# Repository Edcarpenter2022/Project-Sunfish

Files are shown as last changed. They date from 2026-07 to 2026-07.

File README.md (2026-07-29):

# Project-Sunfish
Summer internship project funded by the University of Idaho

**Project Authors:** 
&nbsp;&nbsp;&nbsp;&nbsp;led by Ethan Carpenter, supported by Isaiah Preston and Karson Vordahl 

**Project Supervisors**
&nbsp;&nbsp;&nbsp;&nbsp;Dr. John Shovic and Dr. Marz Everett 

# Overview

&nbsp;&nbsp;&nbsp;&nbsp;Project sunfish is designed to eliminate costly manual sampling of lake Coeur D' Alene. The current process requires a boat trip to the verified satellite locations where there are indicators of harmful algal bloom and heavy metal contents, and the completion of the manual sampling process, which entails collecting each sample individually, at 3 separate depths. Once collected, these samples are then safely, and without contaminating, dumped into a sampling container and then put into a cooler. These samples then are only considered "fresh" for a certain ammount of time before they are not useful for testing. The limitations introduced by this process are the costs and availability of the boat, as well as personnel to operate the boat and take the samples, this operation also has a limited window of time where this can successfully be completed, you cannot take the boat out in the winter time therefore you can not sample the areas in that time, resulting in months of no data collected. 

&nbsp;&nbsp;&nbsp;&nbsp;Sunfish will solve many of these problems and more. Sunfish is a commercially available drone produced by BlueRobotics, and assembled in 2019 by a previous graduate student. It has since been converted to serve this purpose, by designing and retrofitting an automated collection device, for taking samples, as well as adding relevant equipment to create a cohesive device. 

# Phases

There is three main phases to this project

**Phase one:**
&nbsp;&nbsp;&nbsp;&nbsp;Restoring Sunfish back to "factory" configuration and hardware to ensure working components and testing

**Phase two:**
&nbsp;&nbsp;&nbsp;&nbsp;Developing automated collection device and testing

**Phase three:**
&nbsp;&nbsp;&nbsp;&nbsp;Testing components together and collecting samples with sunfish

# Phase One

&nbsp;&nbsp;&nbsp;&nbsp;After retrieving Sunfish from storage, the first task was opening up both enclosures and cleaning all of the components. After sitting in storage for 4-5 years, Sunfish needed a tune-up.



First look at sunfish once pulled from storage

&nbsp;&nbsp;&nbsp;&nbsp;This was done by removing all of the electronics from the enclosures and unseating all of the connections. This was done over the course of 2 days, cleaning and identifying and labeling what each of the components do and where they are located. This allowed me to see what we had and what was unneeded for the project and what components couldn't be sacrificed. 




Electronics, and how they were seated in the main enclosure 



Sunfish with all of the enclosures removed and the electronics off the frame



Electronics cluster after putting everything back together the first time

&nbsp;&nbsp;&nbsp;&nbsp;After the completion of our first successful dive, we identified some small issues and somethings that needed to be fixed. There was a small leak in the main enclosure, during the dive the enclosure took on about 2 tablespoons of water, and one of the main steering thrusters on the front side was non-operational. After further inspection of the non-operational thruster, it appeared that while in storage, there was stagnant water inside the thruster itself on the brushless motor and corroded part of the thrusters battery housing, which caused the motor to then grind on itself and cause damage to the thruster itself. The solution was simple, the non-operational thruster was then moved from the primary steering position, to one of the "extra" slots available on the top side, used for surfacing the drone, this slot was available and did not affect any operation of the drone due to this being part of the optional "heavy thruster configuration" that was purchased, which added an extra 2 thrusters to the surfacing (or top side) portion of the drone. Once swapped the next challenge was identifying and fixing the leak.

&nbsp;&nbsp;&nbsp;&nbsp;Each enclosure housing has three separate parts to it, 2 end caps, which split open to 2 different parts each, and the acrylic tube itself. So, taking apart each component of the housings, each o-ring was replaced and a fresh coat of silicon waterproofing grease was applied. After putting the enclosure back together a pressure test was conducted.(See "Conducting a Pressure Test") Once reached 15mm/hg, it needs to sit for 10 minutes, if the pressure drops below 14mm/hg in that 10 minutes the pressure test is considered a failure and is not safe to put in the water. The sub continually failed these pressure tests, it was pointed out that it might be the enclosure itself, so we swapped the factory 12" acrylic enclosure tube with a 18" acrylic enclosure, nicknamed "Extendo-Tubo". Once replacing the tube, the leak slowed, but it was still failing the pressure tests. To be through, before ordering all new components,  I removed each of the plugs on the back of the enclosure, these seating screws have the wires leading to each of the thrusters as well as the lights and the battery enclosure, protruding from the back, in order to unseat these screws, you have to remove the thrusters from their mounted position. After removing the enclosure bolts, you will see a small o-ring on the inside face of the bolt, all 18 of the o-rings were pulled, replaced and re-greased. They were then screwed back in and torqued by hand to the correct positions. The same was done for the smaller cap screws that are used to hold the 2 different parts of the end caps together. After replacing and torquing them down with a Allen key by hand, Another pressure test was conducted, this test passed and we were ready for our second successful dive (see "Prepping For a Dive").

# Conducting a Pressure Test

&nbsp;&nbsp;&nbsp;&nbsp;In order to conduct a proper vacuum test, you will need the provided vacuum pump. 
- Ensure both the brass male pieces have intact o-rings, and there is no debris on them.
- Seat each male end inside the female ends on the rear of the sub, one on the rear of the main enclosure and the other on the rear of the &nbsp;&nbsp;&nbsp;&nbsp;battery enclosure, the female ends are labeled "Vent"
- Depress the handle of the vacuum pump, effectively removing the air from both enclosures
- To achieve a 15mm/hg readout on the face of the pump, it will take about 300 depressions.
- Once the needle is reading 15mm/hg set a timer for 10 minutes and place the pump somewhere upright and secure (if the pump is not upright, it has been noticed that it will affect the interior pressure for some reason, my guess is that it causes the tube to twist, therefore adding pressure into the enclosure)
- After the 10 minutes is up, if the reading is between 15mm/hg and 14mm/hg, it has passed and you are safe to dive, if the reading is below the 14mm/hg line, it has failed, the first step should be to remove the caps from the enclosures and inspect for debris along the o-rings and repeat the steps above.

# Prepping For a Dive

&nbsp;&nbsp;&nbsp;&nbsp;Congradulations! if you are reading this, you have passed the pressure tests and you are ready to dive.

&nbsp;&nbsp;&nbsp;&nbsp;You will need the following items:
- QGroundControl software installed on your computer, if you're using your personal computer for the dive, or one of the two computers that come with the project has the software already installed. 
- Sunfish itself
- Battery for the sub (this should be charged before the dive fully so it does not die in the water)
- 300 meter tether (this is the spooled tether)
- smaller tether (This tether is wrapped up in the backpack and is used to attach to the spool, and then to the fathomX interface box)
- Fathom X interface box (blue box with a power cord found with it)
- Fathom X interface box power cord
- USB cable that attaches the Fathom X box to your computer
- Xbox controller (wired or wireless)
- Costco wagon (so you can load everything into the wagon and transport to the launch site)
- Sunfish backpack (in this backpack, you will store everything but the sunfish and the 300m tether, inside the backpack is a flat tackle box tray that holds extra components that you might need as well as a wrench that fits the enclosure cap screws. I suggest throwing in a IFIXIT setup so you can easily remove the smaller cap screws)

&nbsp;&nbsp;&nbsp;&nbsp;Before loading everything up in the wagon and making the trek to the launch site, you need to do a couple of things first.

- You will need to ensure that there is no leak in the enclosure, always perform a pressure test before you go out for a dive, even if you tested the day before and it passed, something might have changed overnight that is unseen, always do a pressure right before you leave for launch, or if the sub experiences a lot of jostling around during transport, you will need to perform one at the launch site.
- Boot up QGroundControl and run through the diagnostics, this is done by following these steps which are provided on the BlueRobotics web page
  &nbsp;&nbsp;&nbsp;&nbsp;https://bluerobotics.com/learn/bluerov2-software-setup/#installing-qgroundcontrol
- Once you have completed the Sensor Calibration you need to ensure that in the "Vehicle Setup" tab, under "Frame" you need to ensure the BloueROV2 Heavy/Vectored 6DOF setting is enabled. Remember, that after each calibration setting that is changed, you have to reboot the vehicle entirely.
- After successful completion of these steps, the previously yellow bar on the top left of the screen, will turn green and say "Ready to Launch"
- You then are ready for your launch and are ok to load everything up and head to your launch site

&nbsp;&nbsp;&nbsp;&nbsp;**Launching** 

- When at your launch point, remove everything from the wagon and set up your area
- Make sure you have QGroundControl launched on your computer and the Fathom X Topside Interface plugged into your computer
- On the back of sunfish there is a male plug, plug the matching female end from the spooled tether into that and secure it multiple times with electrical tape to ensure it is fully waterproofed.
- Then connect the looped end of the tether, to the carabiner clip attached to the sub. This makes it so if you need to retrieve it for any reason, you can pull on the tether to reel it back in and not put tension on the plug itself. This is what the tether is made for.
- Hook the smaller tether to the spool side and then to the Fathom X Topside Interface
- Plug in the Xbox controller to your computer.
- You can either choose to place the sunfish in the water gently, or toss it in from the dock if you are on a dock, if you are just on the embankment of a river or the lake, do not throw it, place the drone in the water, so it is all covered, you are going to want to have enough submersion so it can have plenty of room to move up and forward so it doesn't scrape on the bottom.
- It is also a wise idea to have someone in the water with sunfish, two people are preferred if you are launching off a dock, and one person suffices if you are launching in a shallower area.
- Once the sub is fully submerged, click the green "Ready to Launch" button. a small slider arrow will pop up on the bottom of the screen the reads "ready to arm" slide this to the right and the sunfish will arm and then be operational.

&nbsp;&nbsp;&nbsp;&nbsp;Congratulations on your successful dive!

# Automatic Sample Collection Device

&nbsp;&nbsp;&nbsp;&nbsp;The current prototype is what I am calling a "dry prototype" this means its not waterproofed, or ready for diving, only a concept of what this will look like and how it can function, without tackling any of the waterproofing factors. The design consists of a 3D printed honeycomb enclosure that encases a bag with a silicon tube. There is also a "lid" that vertically slides into place over the mouth, that has a channel you can feed the tube through, the tube will end up facing vertically out of the channel, in line with the cover. Inside the tube is placed a ball check valve that has been 3D printed and designed by Ethan Carpenter, this consists of, 3 parts, the "stem", which is a short pipe, which graduates into a wider pipe with a little shelf in the middle for the spring to sit on. the "spring and ball" which is exactly what it sounds like, a spring attached to a ball. Finally the "Cover" this cover has an o-ring attached to it and gets superglued over the spring and ball, creating a seal. 

&nbsp;&nbsp;&nbsp;&nbsp;The plan is to have a Dynamixal servo motor (either the AX-18a or the AX-12a) push down on the ball, releasing the pressure and causing the bag to fill with water. when the sample is completed, it will then release the downward pressure it is holding on the ball and then cause the water flow to be cutoff. This design has been tested without the Dynamixal, and has shown one issue that I have seen. The main issue is that the bag, being deflated and no air inside, so to not affect the buoyancy of the sub, needs some sort of external force placed upon the bag encourage it to open. This is how we avoid using an actual pump at the end to pump the water in. I have thought of attaching somehow a spring to both sidewalls of the bags and then to the outer honeycomb enclosure, that would, when the ball valve is open, force the bag to open, therefore sucking water in and filling it. but I don't think that there is enough force applied by the spring to suck that much water in, this could be because the tube itself is at a 90degree angle, so there is limited room for the water to come in, as well as not enough pressure to pull water inside. The second idea I had, was having a compressed spring inside the bag, it would need to be powerful, and sterile so it docent affect the sample, but if it were compressed inside the bag, and then once the tube is open, it expands, that might create enough force to pull water in, of course then you would have a spring in your sample and then need to get it out. One other idea I had was to create a new bag system that made it so the bag itself was filled with air, and being submerged, this added air might counteract the weight added by the collection device. This would also mean that we would need to add a vent hose out of the top of the bag, so when water comes in, the air isn't escaping through the same hole.



&nbsp;&nbsp;&nbsp;&nbsp;Ball check valve 3D printed Prototype 




&nbsp;&nbsp;&nbsp;&nbsp;3D printed honeycomb enclosure




&nbsp;&nbsp;&nbsp;&nbsp;Lid with sampling tube fed through

# List of components both on and extra for Sunfish 
&nbsp;&nbsp;&nbsp;&nbsp;Components that are currently on and infuse of the sunfish will be bolded, extra components will not be 

- **18 inch enclosure tube**
- 12 inch enclosure tube
- **Acrylic dome lid**
- **rear end cap aluminum lid with 18 port holes**
- **8 inch acrylic battery enclosure**
- **aluminium endcap for battery enclosure**
- **aluminium endcap for battery enclosure with 4 port holes**
- **2 cradles for battery enclosure**
- **2 cradles for main enclosure**
- **6 fairings with buoyancy foam**
- **Pixhawk flight controller** with original box and instructions
- **Raspberry pi 3 + SD Card**
- **Motor terminal block, x2 3 slot housings, and x1 1 slot housing**
- **7 Electronic Speed Controllers (ESC)**
- **Fathom-X Tether Interface Board**
- **Mount to fix camera to front**
- **"Wire guard" located in the "back" of the enclosure between the main "board" and the endcap, used to guide wires through to keep organized**
- **2 lights (one wire lead)**
- **8 thrusters, labeled 1-8, (thruster number 1 is non-operational and has moved to the topside)**
- **Skid plate**
- 2 fairings, one with foam
- **6 7oz ballast weights**
- Big bag of dry&dry Desiccant
- 2 lithium ion batteries (14.8V, 18aH)
- Bag of extra plug screws
- Bag of O-rings
- Bag of plugs for testing your vacuum pump
- 2 Vacuum pumps
- 8 inch aluminium enclosure with both endocarps, this contains a dissolved oxygen sensor with all hardware inside, this has not been tested or touched during this project
- BlueRobotics newtonian gripper
- 3 BlueRobotics depth ping sensors
- Acrylic battery enclosure
- 14 hole (non-threaded) enclosure cap
- 2 full setups for battery enclosure caps
- VGA to USB-A adapter for camera use (removed because it was spliced incorrectly, as well as non-operational and un-needed)
- 3 bags of moisture sensors and relevant pieces
- 2 wired Xbox controllers
- Fathom X topside interface
- Bag of 2 SD cards (copy of sunfish with no access points, has mavlink interface and some test programs from previous student, desktop PI GUI added, Python 3 added
- "Tether" to connect the Dissolved Oxygen sensor to the main enclosure and the PI
- Tackle box insert with extra hardware/ diagnostic tools for dive
- 4 notebooks and manilla envelope of relevant documentation (from previous project leads, both project Catfish and Sunfish)
- External hard drive containing Sunfish dive documents, videos, and reports
- 2 laptops, both containing relevant documentation and were purchased for these projects as well as the chargers
- GoPro used for project, but resides with Marz Everett
- Battery charger with original box
- Sunfish Backpack
    - AC/DC power bank with charger
    - Small tether used to connect spool to Fathom Topside
    - Misc. zip ties
    - Silicon grease
    - Electrical tape
- Costco Tote
    - Minnow drone, disassembled, but some components work and you can use to test code or hardware on it
    - Battery for powering Minnow
- Automatic collection device
- Potentially the Dynamixel servo motors with a Pi 3

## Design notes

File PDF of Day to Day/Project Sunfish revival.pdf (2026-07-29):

Project Sunfish revival

https://bluerobotics.com/learn/bluerov2-assembly/#introduction

5-28-26

- Found laptop passwords
- Took apart electronics inside enclosure and sorted components into different piles
- Cleaned inside the battery enclosure and re-greased o-rings in all acrylic tubes.
- Tore down ROV2 to the “factory” setup
- Identified components added from OG project
- GPS sensor in main electronics tube
- Buck Converter attached to main battery to get power and main board housing inside main tube
- Vernier optical dissolved oxygen probe with complete setup
- Added missing structural bolts to the frame and tube clamps themselves

5-29-26
- Start to put the main board back together
- Removed GPS/compass from pixhawk

●

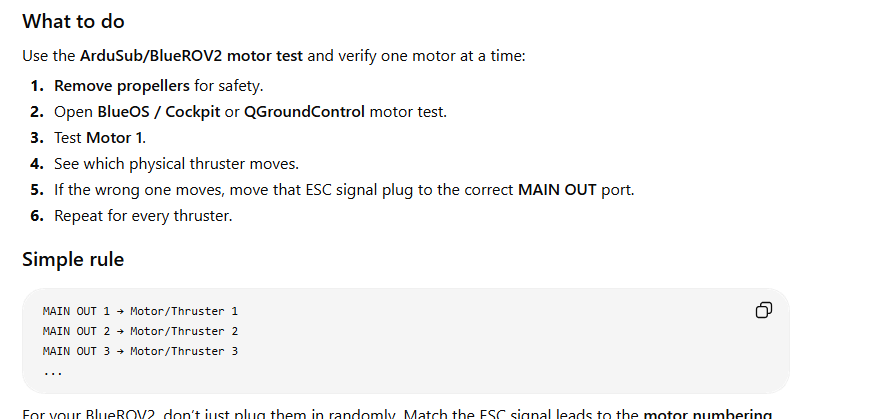
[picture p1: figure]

- Need to do motor test next week
- Replaced water sensors, The “sponge” in the enclosure was expanded meaning there was moisture collected, either from long term storage and the sponge collecting moisture from the air, or actual water introduced to the system. I am more confident that it was moisture pulled from the air due to the storage factors.
- Replaced communication wire on the moisture sensor board as a precaution.
- The board is probably 75% completed!

6-1-26
- Connected the rest of the board and put together the enclosure

6-2-26
- Re-wired the inputs for the Pixhawk
- Added the remaining 2 ESC units and wired them to the 2 thrusters left
- Ensured all connections were tight, re-soldered and shortened some cables.
- Performed vacuum test number 1 : Passed!
- Performed vacuum test number 2 : Passed!
- Removed battery from chassis and placed on charger
- Found issue with tether connection, doesn't connect to itself so we don't know how we can control it.

6-3-26
- Took apart enclosure and added ethernet cable connections, and connection from pi to pixhawk
- Performed vacuum test number 3 : Passed
- Pulled apart board and drew board diagram
- Identified potential issue with tether connection

6-4-26
- Found tether issue
- Made tether pin layout/diagram with connections
- Put board back together and performed vacuum test 4 : Passed
- Connected depth sensor
- Performed vacuum test 5 : Passed
- Set up ground control on Ethan's laptop
- Went through sensor setup
- ROV2 is ready to test in water, test date is thursday june 11th at 6:00am

Relevant documentation

https://bluerobotics.com/wp-content/uploads/2019/02/BlueROV2_heavy.pdf Blue rov2 connections

https://www.ardusub.com/introduction/hardware-options/connection-diagrams.html Connection diagrams

https://bluerobotics.com/learn/bluerov2-software-setup/#installing-qgroundcontrol ground control setup

https://www.ardusub.com/introduction/hardware-options/required-hardware/tether.html hardware setup with tether

https://bluerobotics.com/learn/wl-connector-standard/#tether standard connection

6-5-26
- Logo design

6-8-26
- Performed vacuum test number 6 : Passed
- Plugged vent holes
- Researched plug for loose end connector, best option might be to 3d print one and throw an o-ring in
- Pretty sure I identified the random cable. I believe it is the power/data cable for the doppler velocity log.
- I identified that the manufacturer did not intend the drone to be operated without the tether attached.
- SEACON Underwater Wet-Mate Connectors is the cable used
- The vga cable is used for the doppler sensor, can be removed
- I believe it would be a good idea to add the ping sonar that we currently own, it would add a “failsafe” if the camera feed from the drone fails so we wouldn't crash into anything

6-9-26
- Reviewed all of the flight logs that Amanda completed to determine how and when the camera failed
- Re-wired the camera, fixing the problem unless the camera is fried due to the failed ground wire from the previous use.
- Attempted to unscrew the back caps of the enclosure to add the sonar sensor
- Safely and securely wired sonar sensor into the BLUART converter that allows it to be converted to usb, and then plug into the pi
- Removed the entire serial cable to usb as well as the “extra” tether that is used to communicate to the doppler sensor.
- Re-cracked open the enclosure to adjust orientation so the pixhawk would be facing starboard, therefore the gyroscope would be accurate
- Removed buoyancy foam to remove the final add ons from the previous project
- Re-attached the skid plate for safe sonar mounting, there were no available mounting slots for the sonar that would be safe, so the skid plate is now on
- Zip-tied the cords out of the way for a more clean/unimpeded thruster ability.

6-10-26
- Plugged in Sunfish to battery and connected to QGC to test camera and see if sonar was working.
- Camera does not seem to be working still.

6-11-26
- Prepped for first dive, made sure calibration was good, and all sensors were plugged in
- Checked to make sure all thrusters were plugged in
- Booted up Qground control and tested xbox controller.
- Made a few tweaks with the sunfish and all of the wires and thrusters.

6-12-26
- First dive!!!
- Thruster number 2 does not turn when in water
- There is a grinding noise when in water when turning it to the right, possibly the thruster itself, maybe another thruster grinding on something while attempting to turn
- Sub is a little too heavy, have to remove some of the ballast weights
- There is a small leak in the main enclosure of the sub, after being submerged at different depths for a consistent 10-12 minutes, there was about 5 tablespoons of water in the enclosure, nothing touched the electronics, only the wires, and everything from the outward view is still operational.
- I'm pretty sure the leak was due to a small gap between the cap and the enclosure as well as not lubricating the o-rings with silicon before the dive.
- Need to get more familiar with the controls as well as possibly investing in a wireless xbox controller, the wired one made it decently hard to navigate to a good vantage point while connected to the laptop
- Need to get a better look at the screen while diving to see what controls i can see and sensors are working, i know on the blue robotics page, there is a new operating system where you can customize your home screen and put different readouts/panels in the main view, worth looking into
- Need to research new thrusters, a new thruster from blue robotics with an extra fin is $240, there might be some in longterm storage that we can find.

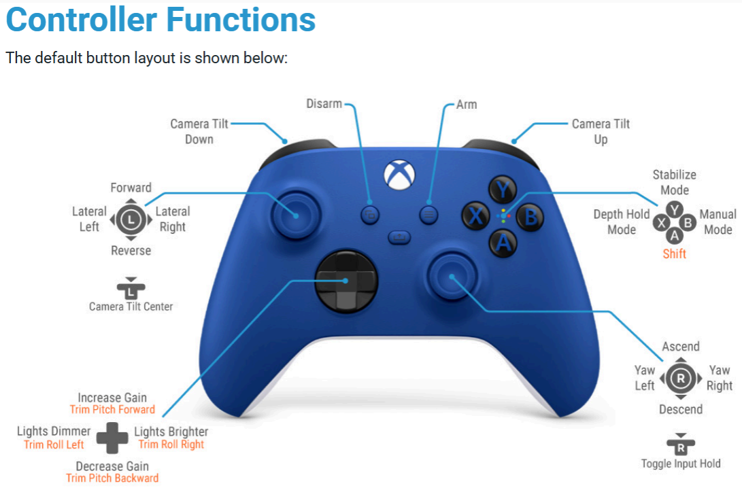
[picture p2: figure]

- Above is the controller mapping
- I also dont know if the camera tilt works, I am pretty sure that i can test it outside of water though, The only part that we need might be the actual camera from blue robotics, which is $134.40 without shipping domestic shipping is $6.50, 2 day shipping is $35.90

6-16-26
- Dive date!!!
- Sunfish did not pass the leak test, there was too severe of a leak to safely perform the test today. Karson and I replaced the tubes for the vacuum pump as they were leaking, as well as took off the enclosure lids on either side, both the domed one and the corded one. And inspected for any hairs or debris that caused the improper test. Could not find anything. I suspect that the leak is coming from some sort of crack in the acrylic tubing, there are many scratches on the tubing itself and that could cause a leak. There was also a small leak that looked like it was allowing water in the underside of the sub, in the same position as the last leak, so I am confused as to why this is still happening. When I return on Monday the 22nd of June, I will investigate further and try to find the issue.

6-22-26
- Took off the 12 inch acrylic tube that I thought had the leak and replaced it with the 18 inch acrylic tube. For the 18” tube I made a board mount like the one attached to the camera to make it more stable for the actual board itself
- Vacuum tested the 18” tube and the pump was saying there was another leak. It wasn't constant but it was also hard to get up to pressure, making me think that it is the actual vacuum pump that is the issue. There are some other vacuum pumps on amazon that are available, there is the style of the one we currently have for around 15-20 and the more robust one for 57 without any tubes i think. Will investigate more tomorrow

6-23-26
- Tested vacuum for 18” tube and still failed, next step is to replace battery housing
- 3D printed and modled different camera mounting systems, as well as created internal skeleton to help with the stability of the camera in general

6-24-26
- Performed testing on why the camera was not working, turns out its the actual camera itself, not the board. Need to look into buying a new tested camera
- Hooked up QGround Control to Sunfish and tried to map out what channel the lights are on and decided that the lights are indeed not working, either from frankenstaining the wires or bad wiring in general. Need to look into further
- Replaced battery housing enclosure
- Preformed vacuum tests to ensure vacuum

6-25-26
- Pulled cap plugs out and re-greased and replaced some of the o rings on certain plugs.
- Opened the enclosure and un-seated wires, re-routed most of the wires to make it a cleaner fit inside the enclosure, no more rubbing wires, plus that allowed me to ensure things were connected properly as well as double check the thruster inputs
- Opened most cap o-rings and replaced grease in them, some used the bad type of grease, cleaned and replaced all

6-26-26
- Put enclosure back together with everything wired together, this both fixes the orientation of the pixhawk for the gps issue that we were having, as well as it allows me to ensure that the seals on the inside are tight
- Tested each individual tube with the vacuum pump, turns out i think that it is the connection between the pump itself, we found an stl file that we are printing currently to test the vacuum out on.
- Will try and update on monday

6-29-26
- Attempted to find and fix pressure leak, unsuccessful, will try again tomorrow

7-1-26
- Re sealed enclosure and connected all of the bulkhead connectors
- Small leak is still there, but definitely slower, I don't really know what it could be outside of that besides some connection issue, but i will figure that out on monday

7-9-26
- Put all dome mounted plugs back in with re-greased O-rings and torqued down the cap screws with an allen wrench, performed the first pressure test after re-assembly : PASSED!

7-10-26
- Took time lapse video of putting sunfish back together for social media, re-wired everything and seated everything back together. Performed Pressure test #2 : PASSED!

7-13-26
- Preparation for dive #2
- Dive #2 was a success!
- Thruster number one is still non operational, and therefore causes the sunfish to descend into water unevenly
- Thruster 2 looks like it is always on

7-20-26
- Work on developing the automatic water collection system
- Idea: Have a 3D printed honeycomb cage around a scientific ziploc bag. The bag needs to have a relatively wide opening, about the width of a quarter. This is attached to the ring of the cage. Attached to the cage, there is a flip top lid with a servo motor attached on top, or on the side. There is a spring holding the lid closed with constant pressure. The servo motor will then open the flip lid and let water in, when it is full, after a certain amount of time, the motor will release and the spring will cause the lid to snap shut, locking the water in the bag. These need to be all individually working, and there needs to be 3 different mounted collection systems. The bag will also need to be easily removable and replaceable without letting any contaminants come in contact with the sample
- 3D printed collection housing cage, and developed one idea for the lid
- Coded three servos to operate off one pi

7-21-26
- Modeled and Printed another design for the lid which allows a catheter type silicone tube to go through it and then be clamped off
- Coded a servo to clamp the tube, release the clamp to have the bag fill with water, and then clamp it again. The problem with this is if there is any movement in the servo itself, the positioning will be off and therefore not create a closure in the tube.
- Marz thought getting a different, more powerful servo would be a good idea, She is removing the one from the Boeing robot downstairs.

7-24-26
- With the help of Marz, figures out how to wire the dynamixels correctly and then also code them to starting position, 90 degrees closed, and then back to starting position. The positioning of the motors itself is repeatable and able to be produced more than once.
- Polished ideas for collection system, we will end up using a rubber duck bill valve to keep the water out, then the servo motor will apply pressure against it and then open it, when collection is complete, the servo will then remove pressure and seal the collection bag.

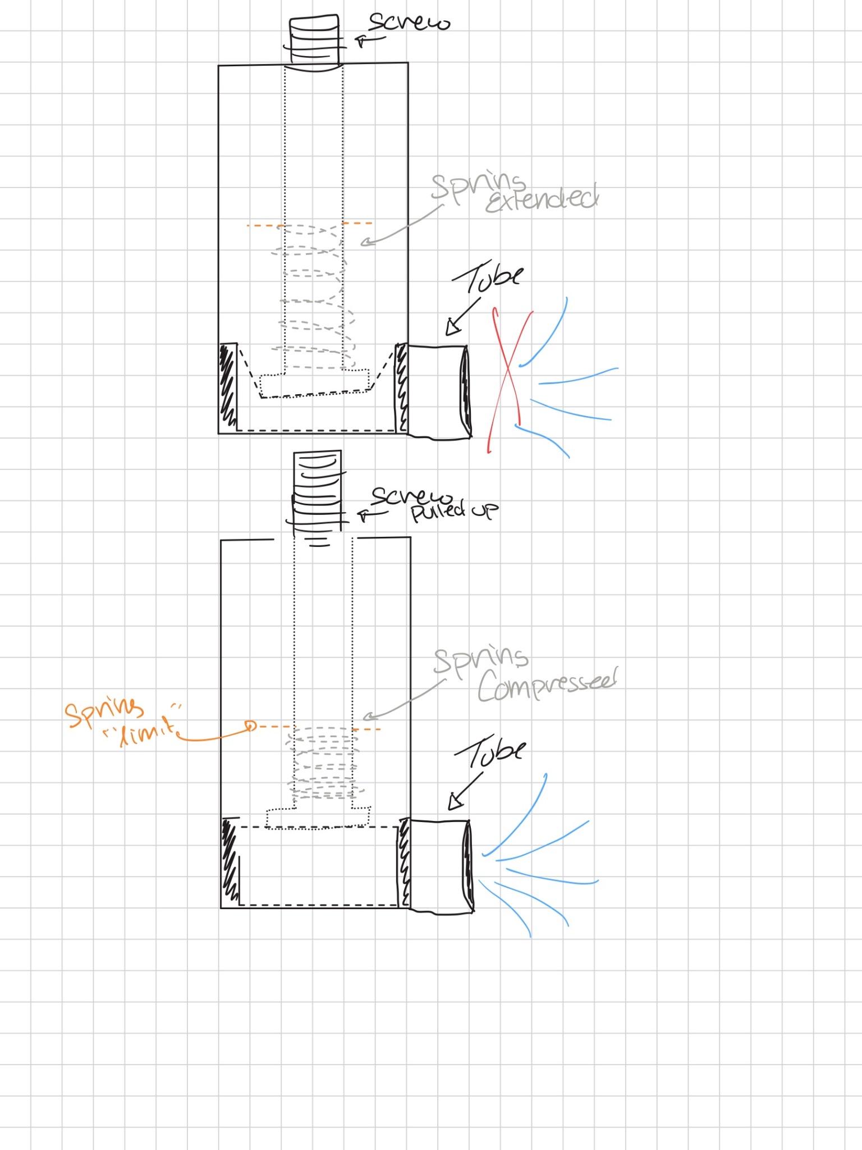
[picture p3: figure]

●

7-28-26
- Developed 2 prototypes of the sampling device, also developed and implemented a ball check valve to slip inside the collection tube, this will allow the bag to not be contaminated by any other samples.
- Started writing Github repository for the project.

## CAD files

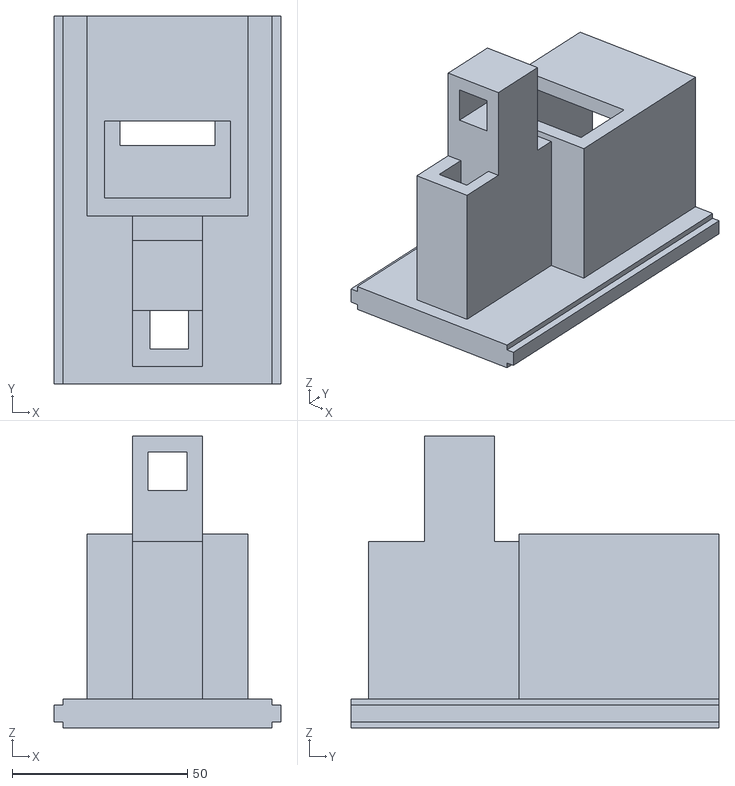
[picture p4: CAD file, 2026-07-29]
STL-Files/Lid prototype 4.stl
64.8 x 105.0 x 83.2

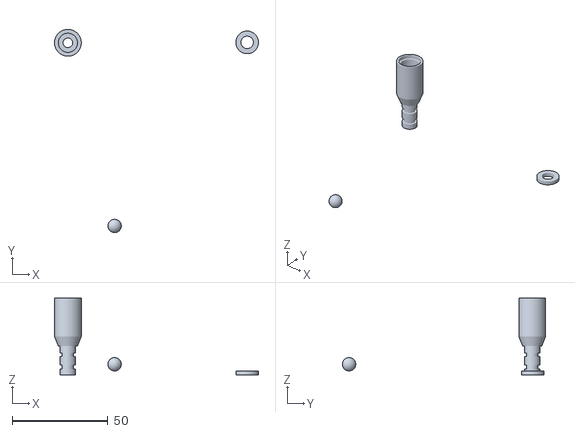
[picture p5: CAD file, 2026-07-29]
STL-Files/ball check valve 4.3.stl
106.6 x 106.2 x 40.0

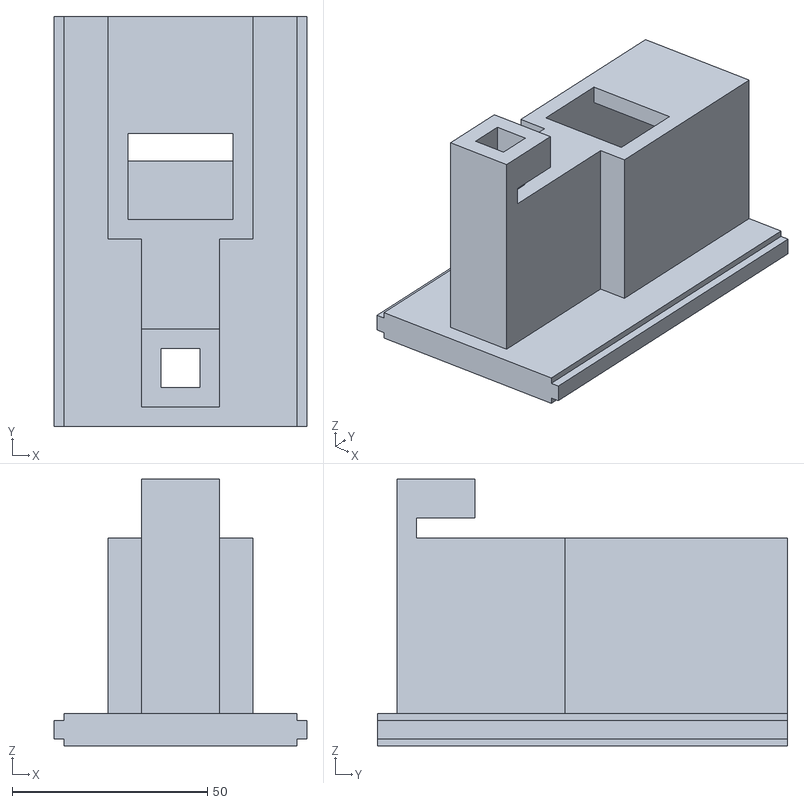
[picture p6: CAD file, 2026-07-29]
STL-Files/cover prototype 2.stl
64.8 x 105.0 x 68.2

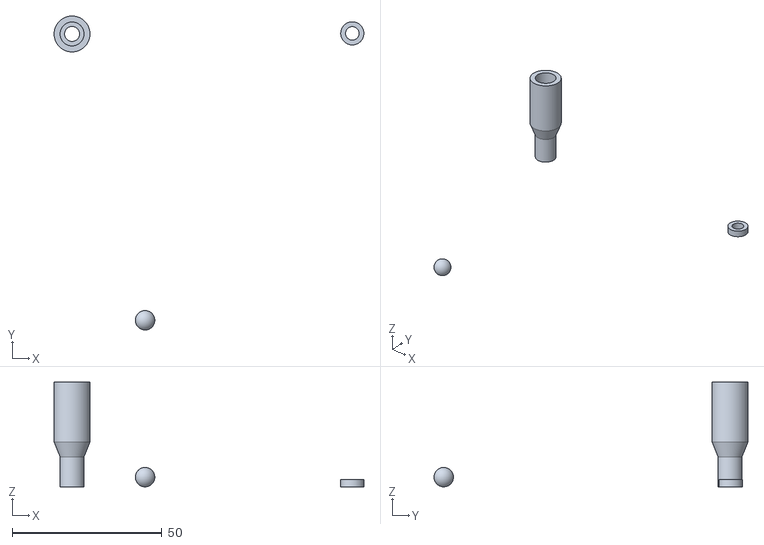
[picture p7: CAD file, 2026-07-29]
STL-Files/Check valve prototype 4.2.stl
103.5 x 104.9 x 35.0

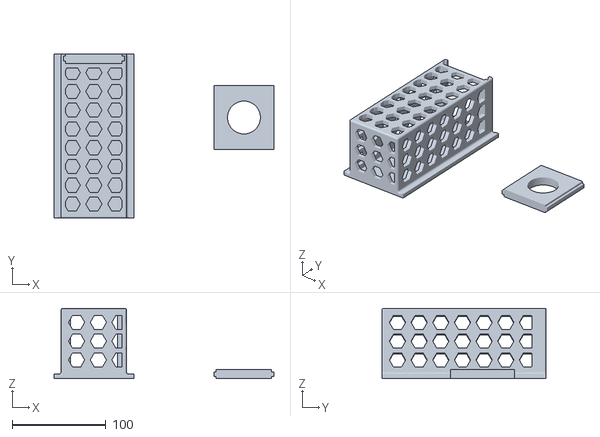
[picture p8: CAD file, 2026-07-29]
STL-Files/Collection system enclosure Prototype 1.stl
234.4 x 175.0 x 75.0

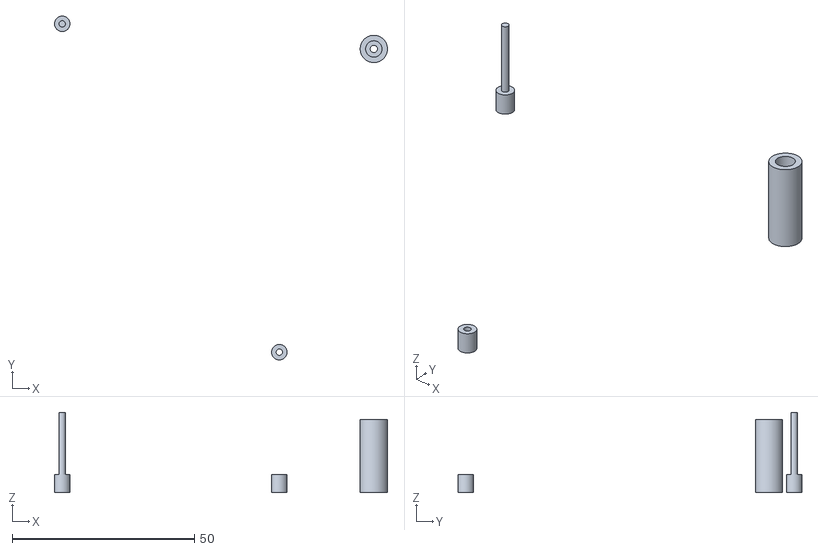
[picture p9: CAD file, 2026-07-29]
STL-Files/Check valce prototype 2.stl
91.4 x 94.3 x 22.0

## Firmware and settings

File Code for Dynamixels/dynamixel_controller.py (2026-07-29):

#! /usr/bin/env python
import numpy as np
import rospy
from dynamixel_sdk import *
import os
import time
import sys
import ctypes

open = [484, 558]
close = [710, 310]

#Notes:
#I think to get this to protocol 2 the major change is just the packetHandler. This is something to look into. 

#This info is for our SPECIFIC gripper (not necessarily generalizable)
ids = [1, 2]
limits = [[484, 729], [320, 558]]
#ct stands for control table
AX_ct_names = ["Model_Number", "Firmware_Version", "ID", "Baud_Rate", "Return_Delay_Time", "CW_Angle_Limit",
                           "CCW_Angle_Limit", "Temperature_Limit", "Min_Voltage_Limit", "Max_Voltage_Limit", 
                           "Max_Torque", "Status_Return_Level", "Alarm_LED", "Shutdown", "Torque_Enable",
                           "LED", "CW_Compliance_Margin", "CCW_Compliance_Margin", "CW_Compliance_Slope",
                           "CCW_Compliance_Slope", "Goal_Position", "Moving_Speed", "Torque_Limit",
                           "Present_Position", "Present_Speed", "Present_Load", "Present_Voltage", "Present Temperature",
                           "Registered", "Moving", "Lock", "Punch"]
AX_ct_addr = [0, 2, 3, 4, 5, 6, 8, 11, 12, 13, 14, 16, 17, 18, 24, 25, 26, 27, 28, 29, 30, 32, 34, 
                              36, 38, 40, 42, 43, 44, 46, 47, 48]
AX_ct_len = [2, 1, 1, 1, 1, 2, 2, 1, 1, 1, 2, 1, 1, 1, 1, 1, 1, 1, 1, 1, 2, 2, 2, 2, 2, 2, 1, 1, 1, 1, 1, 2]


#This class assumes you are using a chain of the EXACT same type of motors. It cannot handle multiple motor types in one chain at this time. 
class dynamixelMotorControl:
   def __init__(self, type, baudrate, portName, protocol, speed = 100, list_of_ids=ids, list_of_limits=limits, threshold=10):
      #Type initialization
      self.type = type
      if type == "AX-18A" or type == "AX-18F":
         #Assign the motor specific lists
         self.ct_names = AX_ct_names
         self.ct_addr = AX_ct_addr
         self.ct_len = AX_ct_len
         self.speed = 100
      else:
         print("ERROR: Unknown Motor Type. Unable to initialize motor.")
         return 
      
      #Motor specific values setup
      self.ids = ids
      self.limits = limits
      self.torque_enable_addr = AX_ct_addr[AX_ct_names.index("Torque_Enable")] 
      self.goal_position_addr = AX_ct_addr[AX_ct_names.index("Goal_Position")]
      self.present_position_addr = AX_ct_addr[AX_ct_names.index("Present_Position")]
      self.goal_position_len = AX_ct_len[AX_ct_names.index("Goal_Position")]
      self.present_position_len = AX_ct_len[AX_ct_names.index("Present_Position")]
      
      #communication setup
      self.baudrate = baudrate
      self.portName = portName
      self.protocol = protocol

      #From SDK
      self.portHandler = PortHandler(self.portName)
      self.packetHandler = PacketHandler(self.protocol)
      
      #These lists will keep track of the writer objects we decided to use for the dynamixels
      self.writer_names = []
      self.writer_objects = []
      #Bulk Reader Object, for Protocol 1
      self.groupBulkRead = GroupBulkRead(self.portHandler, self.packetHandler)

      #Misc
      self.moving_threshold = threshold
      self.torque_enable = 1
      self.torque_disable = 0

   #Take find the address at the specified control table name 
   def getAddress(self, ct_name):
      return self.ct_addr[self.ct_names.index(ct_name)]

   #Find the bytelength at the specified control table name
   def getLength(self, ct_name):
      return self.ct_len[self.ct_names.index(ct_name)]

   #Begin the motor. Setup and open the port, read in the motor limits, set the initial motor speeds
   def begin(self):
      #This is also from the SDK
      print()
      # Open port
      if self.portHandler.openPort():
         print("Succeeded to open the port")
      else:
         print("Failed to open the port")        
         #quit()
      #Set the port's baudrate
      if self.portHandler.setBaudRate(self.baudrate):
         print("Baudrate Set.")
      else:
         print("Failed to Set Baudrate")
         #quit()
         return
      
      #Write the inital speed to the dynamixels
      for i in range(0, len(self.ids)):
         self.motorWrite(self.ids[i], "Moving_Speed", self.speed)
      
      #Write the motor limits to the dynamixel 
      for i in range(0, len(self.ids)):
         self.motorWrite(self.ids[i], "CW_Angle_Limit", self.limits[i][0])
         self.motorWrite(self.ids[i], "CCW_Angle_Limit", self.limits[i][1])
      
      #Enable the torque on all of the dynamixel motors in our chain. 
      for i in range(0, len(self.ids)):
         self.motorWrite(self.ids[i], "Torque_Enable", self.torque_enable)
      print()
      print("Motor is Ready to Begin")

   #Cutoff access to the motor -- Disable the motor's torque and close the comm port
   def end(self):
      for i in range(0, len(self.ids)):
         self.motorWrite(self.ids[i], "Torque_Enable", self.torque_disable)
      self.portHandler.closePort()
      print("Motor Access Off")
  
  #Ping the motors by spedified ID, get back the model number
   def ping(self, Ids):
      for i in range(0, len(Ids)):
         dxl_model_number, dxl_comm_result, dxl_error = self.packetHandler.ping(self.portHandler, Ids[i])
         if dxl_comm_result != COMM_SUCCESS:
            print("%s" % self.packetHandler.getTxRxResult(dxl_comm_result))
         elif dxl_error != 0:
            print("%s" % self.packetHandler.getRxPacketError(dxl_error))
         else:
            print("[ID:%03d] ping Succeeded. Dynamixel model number : %d" % (Ids[i], dxl_model_number))

   #Read 1 thing from a dynamixel motor (not synced)
   def motorRead(self, id, name):
         size = self.getLength(name)
         addr = self.getAddress(name)
         if size == 1:
            data, dxl_comm_result, dxl_error = self.packetHandler.read1ByteTxRx(self.portHandler, id, addr)
         elif size == 2:
            data, dxl_comm_result, dxl_error = self.packetHandler.read2ByteTxRx(self.portHandler, id, addr)
         elif size == 4:
            data, dxl_comm_result, dxl_error = self.packetHandler.read4ByteTxRx(self.portHandler, id, addr)
         
         if dxl_comm_result != COMM_SUCCESS:
               print("%s" % self.packetHandler.getTxRxResult(dxl_comm_result))
         elif dxl_error != 0:
               print("%s" % self.packetHandler.getRxPacketError(dxl_error))
         return data

   #This doesn't work in for AX models in Protocol 1.0. 
   #Synchronized Read of Several Values
   def motorSyncRead(self, Ids, name):
      addr = self.getAddress(name)
      length = self.getLength(name)
      print(addr)
      print(length)
      
      #Add the parameters for the bulk read
      for i in range(0, len(Ids)):
         dxl_add_result = self.groupBulkRead.addParam(Ids[i], addr, length)
         if dxl_add_result != True:
               print("[ID:%03d] groupBulkRead addparam failed" % Ids[i])
               return
         else:
            print("Added the parameter successfully")
      #time.sleep(1)
      #Do the bulk read
    
      dxl_result = self.groupBulkRead.txRxPacket()
      if dxl_result != COMM_SUCCESS:
            print("%s" % self.packetHandler.getTxRxResult(dxl_result))
           
      #Actually get and print the data
      toReturn = []
      for i in range(0, len(Ids)):
         get_data_result = self.groupBulkRead.isAvailable(Ids[i], addr, length)
         if get_data_result != True:
            print("[ID:%03d] groupBulkRead getdata failed" % Ids[i])
         else:
            val = self.groupBulkRead.getData(Ids[i], addr, length)
            toReturn.append(val)
            print("Value of ", name, "For Motor", Ids[i], "is ", val)
      self.groupBulkRead.clearParam()
      return toReturn
      

   #Write 1 Thing to a Dynamixel Motor (not synced)
   def motorWrite(self, id, name, value):
      size = self.getLength(name)
      addr = self.getAddress(name)
      if size == 1:
         dxl_result, dxl_error = self.packetHandler.write1ByteTxRx(self.portHandler, id, addr, value)
      elif size == 2:
         dxl_result, dxl_error = self.packetHandler.write2ByteTxRx(self.portHandler, id, addr, value)
      elif size == 4:
         dxl_result, dxl_error = self.packetHandler.write4ByteTxRx(self.portHandler, id, addr, value)
      
      #Handle Any Errors
      if dxl_result != COMM_SUCCESS:
            print("%s" % self.packetHandler.getTxRxResult(dxl_result))
      elif dxl_error != 0:
            print("%s" % self.packetHandler.getRxPacketError(dxl_error))
      else:
            print("Successfully wrote", value, "of ", name, " to Dynamixel#%d " % id)
 

   #Sync Write to the dynamixel motor. Multiple values stored in. 
   def motorSyncWrite(self, Ids, values, byteSize, writerObject):
      #Get the values into the correct format and add them to our paramters
      for i in range(0, len(Ids)):
         # Allocate goal position value into byte array -- GO BACK AND CHANGE THIS TO BE MORE FLEXIBLE, EVENTUALLY.
         if (byteSize == 2):
            #You need to investigate this. It's weird. 
            position = [DXL_LOBYTE(DXL_LOWORD(values[i])), DXL_HIBYTE(DXL_LOWORD(values[i]))]
         else:
            position = [DXL_LOBYTE(DXL_LOWORD(values[i])), DXL_HIBYTE(DXL_LOWORD(values[i])), DXL_LOBYTE(DXL_LOWORD(values[i])), DXL_HIBYTE(DXL_LOWORD(values[i]))]  
         #Add the parameters
         dxl_result = writerObject.addParam(Ids[i], position)
         if dxl_result != True:
            print("[ID:%03d] groupSyncWrite addparam failed" % Ids[i])
     
      #Actually Write the Values
      dxl_result = writerObject.txPacket()
      if dxl_result != COMM_SUCCESS:
         print("%s" % self.packetHandler.getTxRxResult(dxl_result))
      # Clear syncwrite parameter storage
      else:
         print("Successfully wrote", values, "to ", Ids)
      writerObject.clearParam()

  #Function to use when doing a synchronized write
   def syncWrite(self, Ids, name, values, wait=True, printStatus=True):
      addr = self.getAddress(name)
      length = self.getLength(name)
      threshold = 10
      if name in self.writer_names:
         writer = self.writer_objects[self.writer_names.index(name)]
      else:
         #Make a new writer object:
         print("Creating a new writer object")
         newObj = GroupSyncWrite(self.portHandler, self.packetHandler, addr, length)
         self.writer_objects.append(newObj)
         self.writer_names.append(name)
         writer = newObj
      self.motorSyncWrite(Ids, values, length, writer)
      if (wait == True):
         cont = 0
         while cont < len(Ids):
            #continue variable
            cont = 0
            newValues = []
            if name == "Goal_Position": #Special case specfific to movement
               #Read the Moving Status
               for i in range(0, len(Ids)):
                  newValues.append(self.motorRead(Ids[i], "Moving"))
                  #If the arm isn't moving, we can continue
                  if newValues[i] == 0:
                      cont += 1
            #Otherwise we'll use a threshold value to determine when to return from this function
            else: 
               for i in range(0, len(Ids)):
                  newValues.append(self.motorRead(Ids[i], name))
                  if (abs(values[i]) - newValues[i]) < self.moving_threshold:
                     cont += 1
            #We can print current position, goal position, speed, load, and voltage 
            if printStatus == True:
               self.printStatus(Ids)

   #Print Info about the init's you made for the motor
   def printInfo(self):
      print()
      print("Motor Type: ", self.type)
      print("Communication:")
      print("Baudrate:", self.baudrate)
      print("PortName:", self.portName)
      print("Protocol:", self.protocol)
      print("Motor Specific Info: ")
      print("Motor ID's", self.ids)
      print("Motor Min and Max Limits", self.limits)
      print("Moving Threshold", self.moving_threshold)
      print()

   #Read in and Print current position, goal position, speed, load, voltage
   def printStatus(self, Ids):
      current_positions = []
      goal_positions = []
      current_speed = []
      current_load = []
      current_voltage = []
      for i in range(0, len(Ids)):
         current_positions.append(self.motorRead(Ids[i], "Present_Position"))
         goal_positions.append(self.motorRead(Ids[i], "Goal_Position"))
         current_speed.append(self.motorRead(Ids[i], "Present_Speed"))
         current_load.append(self.motorRead(Ids[i], "Present_Load"))
         current_voltage.append(self.motorRead(Ids[i], "Present_Voltage"))
      print("------------------------Status-----------------------------")
      print("Current Positions", current_positions)
      print("Goal Positions", goal_positions)
      print("Current Speed", current_speed)
      print("Current Load", current_load)
      print("Current Voltage", current_voltage)
      print("-----------------------------------------------------------")
   


#Main Program 
def main():
   init_speed = 100
   gripper = dynamixelMotorControl("AX-18F", 1000000, '/dev/ttyUSB0', 1.0)
   gripper.printInfo()
   gripper.begin()
   #waveHi(gripper)
   #openShut(gripper)
   gripper.ping([1, 2])

   gripper.end()

if __name__=="__main__":
    main()

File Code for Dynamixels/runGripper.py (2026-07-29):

#! /usr/bin/env python
import numpy as np


import dynamixel_controller as dmxl

open = [484, 558]
close = [710, 310]

#Gripper waves to you slowly
def waveHi(gripper):
   init_speed = 100
   wave1 = [484, 310]
   wave2 = [710, 558]

   while (init_speed < 150):
      gripper.syncWrite([1, 2], "Goal_Position", wave1)
      gripper.syncWrite([1, 2], "Goal_Position", wave2)
      init_speed += 10
      gripper.syncWrite([1, 2], "Moving_Speed", [init_speed, init_speed])

#Gripper opens and shuts, gets faster and faster
def openShut(gripper):
   init_speed = 100
   while (init_speed < 1000):
      gripper.syncWrite([1, 2], "Goal_Position", open)
      #time.sleep(5)
      gripper.syncWrite([1, 2], "Goal_Position", close)
      init_speed += 50
      gripper.syncWrite([1, 2], "Moving_Speed", [init_speed, init_speed])

#Main Program 
def main():
   init_speed = 100
   #Initialize motor model AX-18F with a baud rate of 1000000 on port USB0 using packet protocol 1.0
   gripper = dmxl.dynamixelMotorControl("AX-18F", 1000000, '/dev/ttyUSB0', 1.0)
   gripper.printInfo()
   gripper.begin()


   #waveHi(gripper)
   openShut(gripper)
   #gripper.ping([1, 2])

   gripper.end()

if __name__=="__main__":
    main()

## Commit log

2026-07-29 Create Automated Collection Device
2026-07-29 Update and rename Automated Collection Device to STL files
